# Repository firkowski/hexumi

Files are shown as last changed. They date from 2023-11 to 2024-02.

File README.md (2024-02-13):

# Hexumi
---
Hexumi is a low-cost 3D-printed 18 DoF walking hexapod robot built using Raspberry Pi and ROS2.

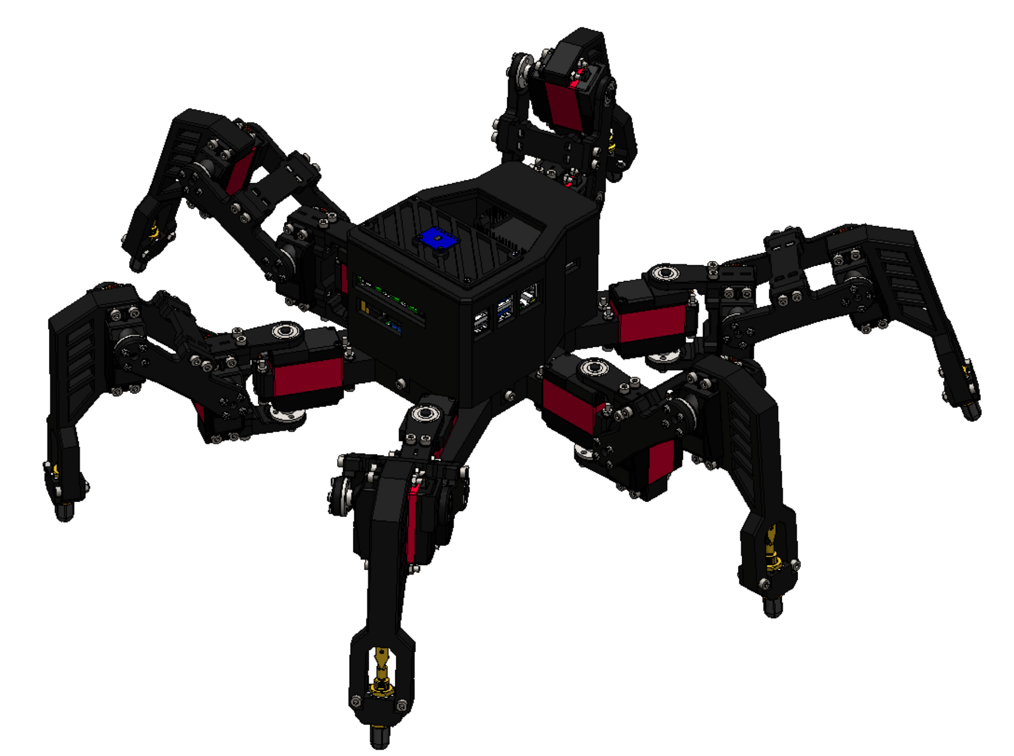
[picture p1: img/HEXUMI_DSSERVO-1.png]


---
## Acknowledgements
The code for Pimoroni Servo2040 servo driver is based on the [C/C++ Pimoroni Pico library](https://github.com/pimoroni/pimoroni-pico) and [micro-ROS](https://github.com/micro-ROS/).

## Documentation
I am currently working on the documentation, assembly instructions, and installation guide, which will be available shortly.

#### Installation (WIP)
The `main` branch contains CAD and STL files. It's meant to be cloned to the development machine.

The `hexumi-base` branch contains minimal code meant to be run directly on the robot.

## Development
For in-depth insights into the development process and detailed build instructions, please refer to my 2023 paper, "Design and Simulation of a Six-Legged Walking Robot", accessible on my [ResearchGate profile](https://www.researchgate.net/profile/Maksymilian-Firkowski/research). Even if you don't intend to replicate Hexumi, the paper provides a valuable roadmap for designing your robot.

## Dependencies
Software in this repo requires ROS2 Humble to run.

To use the Pro Controller, you will have to install [joycond](https://github.com/DanielOgorchock/joycond) on your Raspberry Pi.

Building servo driver's firmware requires the [Pico SDK](https://github.com/raspberrypi/pico-sdk) and [micro-ros-setup](https://github.com/micro-ROS/micro_ros_setup). Remember to export `PICO_SDK_PATH` to point to the folder with the SDK.

---
## Licensing

Code is shared under the MIT license. For details, see [src/LICENSE](src/LICENSE) or [uros/LICENSE](uros/LICENSE).

CAD files, STL files, and the wiring diagram are shared under the Creative Commons Attribution 4.0 License. For details, see [CAD/LICENSE](CAD/LICENSE), [STL/LICENSE](STL/LICENSE), or [img/LICENSE](img/LICENSE).

---
## Why Hexumi?
I designed Hexumi as the subject of my Mechanical Engineering BSc thesis at the Lodz University of Technology, driven by two significant events: the COVID-19 pandemic and the rise of consumer AI. Over the past years, millions of people lost the ability to interact with the outside world due to lockdowns. Simultaneously, the threat of machine learning systems replacing online work loomed. Existing robotic tools for physical labor were either too expensive or lacked sophistication, making them inaccessible to the average person. Thus, I aimed to contribute to the development of affordable robotic solutions for research, education, and entertainment, with the potential to democratize access to mobile and dextrous robots.

### Key Features

- **Cost-efficiency and Accessibility:** Hexumi is designed for easy replication using consumer-grade 3D printing techniques and off-the-shelf electronic components. Depending on your circumstances and 3D printer availability, the build cost can be as low as 300 EUR.

- **Material-efficiency and Sustainability:** The mechanical elements require minimal 3D printing supports, reducing material waste and improving sustainability. Its modular structure ensures that you only need to print minor components when replacements are necessary.

- **Modifiability and Repairability:** Hexumi's components can be easily replaced, whether due to failure or modification. In many cases, only a small amount of material needs to be used for replacements. For example, if you want to change the ground-contact sensors, you only need to modify the tips of the tibias, not the entire links.

- **Software and Sensor Expandability:** Hexumi is designed to operate with the Robot Operating System, preferably ROS2, as its RP2040-based servo driver is well-suited for Micro-ROS. The robot's housing design, a 5V USB power port, and 1.5kg static payload capacity allow mounting additional sensors, such as LIDARs, cameras, IMUs, and more.

- **Ease of Use:** Hexumi was designed to be both modifiable and easy to use. Peripheral components, such as the charging port, provide a simple out-of-the-box experience for a novice user.

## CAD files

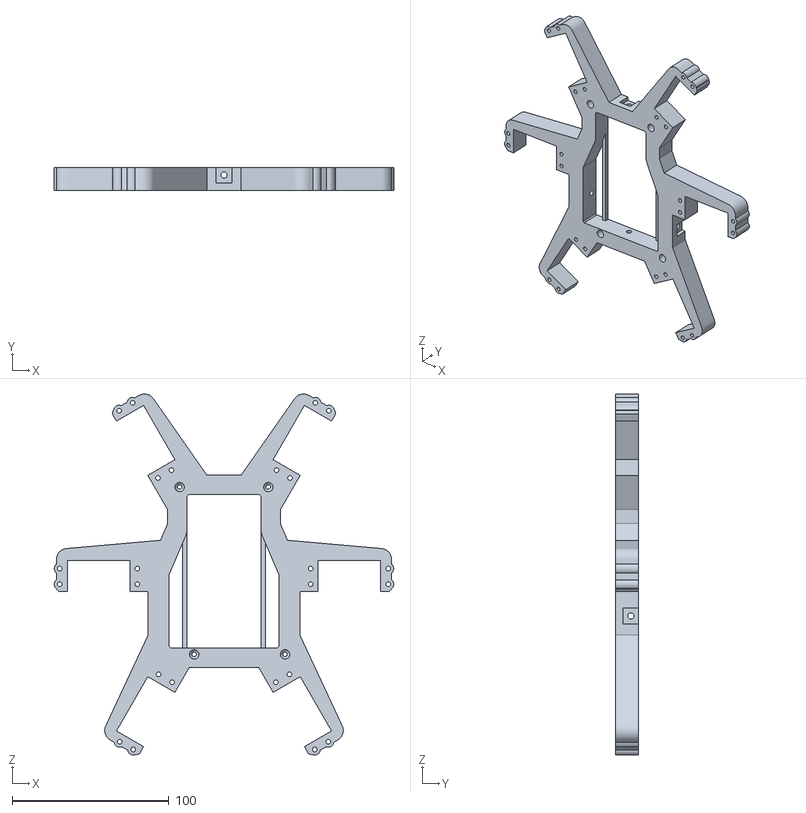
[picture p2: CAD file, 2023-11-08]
STL/MAIN_FRAME.STL
216.8 x 15.0 x 230.5

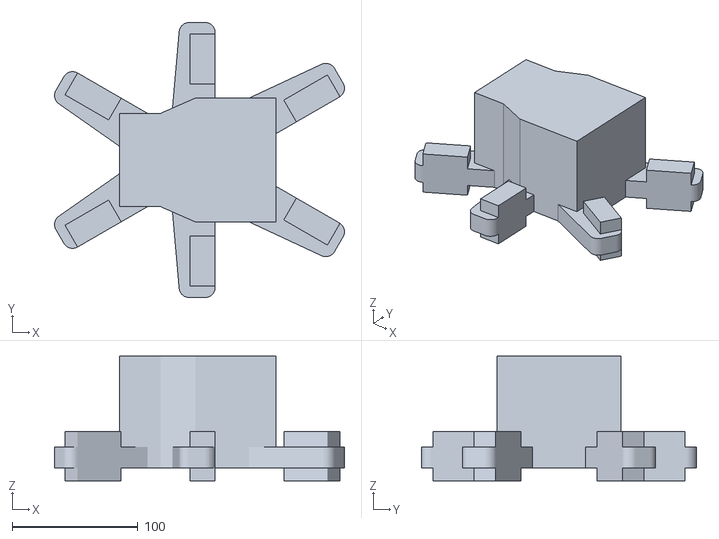
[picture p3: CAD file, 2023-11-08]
src/hexumi_description/meshes/collision/BODY_COLLISIONS.stl
230.3 x 218.5 x 99.0

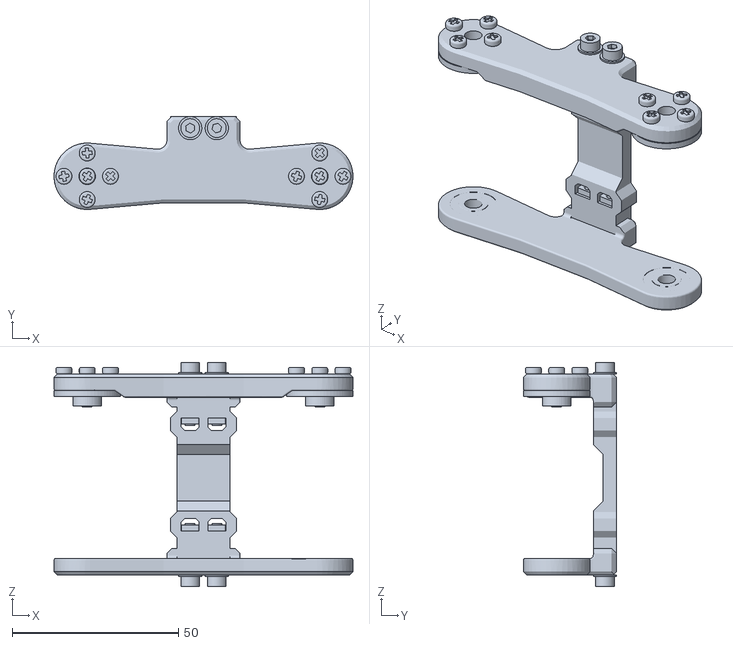
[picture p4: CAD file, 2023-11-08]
src/hexumi_description/meshes/visual/FEMUR_L.stl
90.0 x 28.0 x 67.5

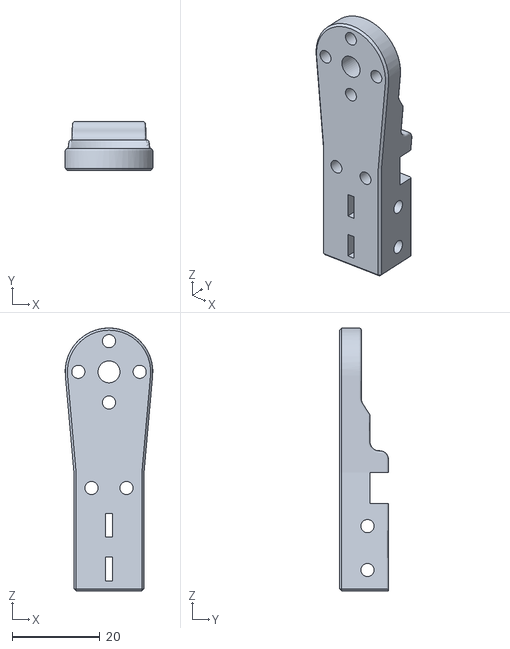
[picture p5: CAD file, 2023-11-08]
STL/COXA_SERVO.STL
20.0 x 11.2 x 60.0

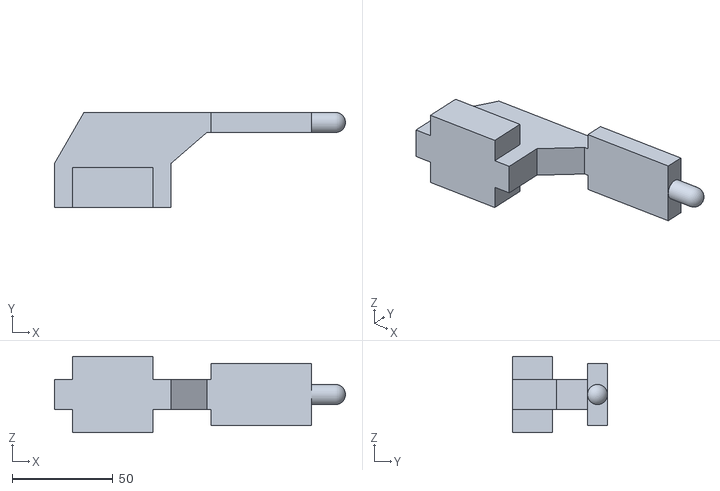
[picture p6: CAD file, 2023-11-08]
src/hexumi_description/meshes/collision/TIBIA_COLLISIONS.stl
144.7 x 47.4 x 38.0

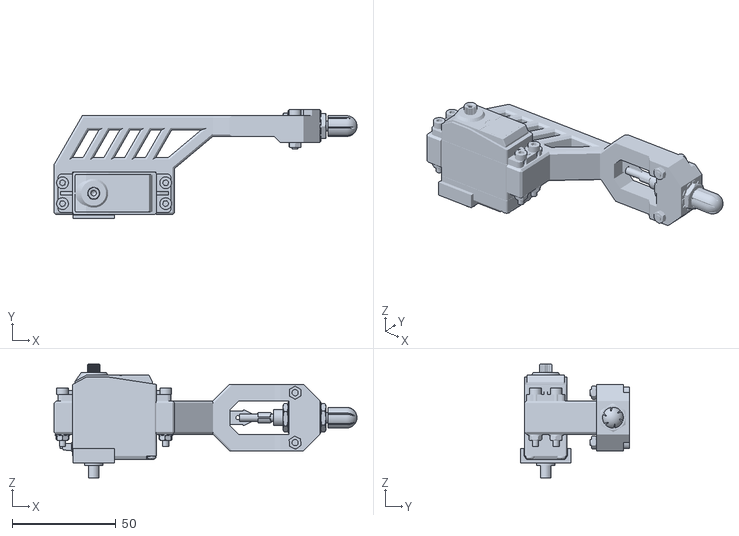
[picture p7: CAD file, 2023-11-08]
src/hexumi_description/meshes/visual/TIBIA_L.stl
145.7 x 52.5 x 54.8

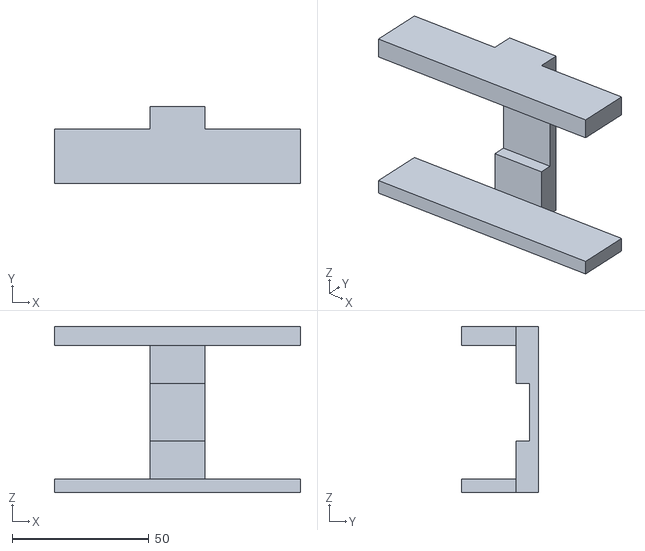
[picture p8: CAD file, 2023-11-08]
src/hexumi_description/meshes/collision/FEMUR_L_COLLISIONS.stl
90.0 x 28.2 x 60.9

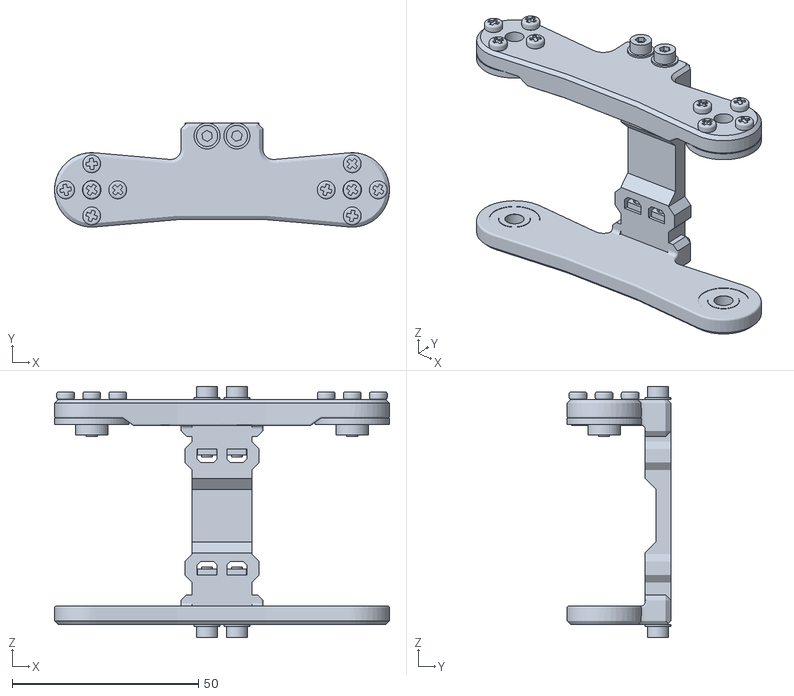
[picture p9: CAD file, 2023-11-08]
src/hexumi_description/meshes/visual/FEMUR.stl
90.0 x 28.0 x 67.5

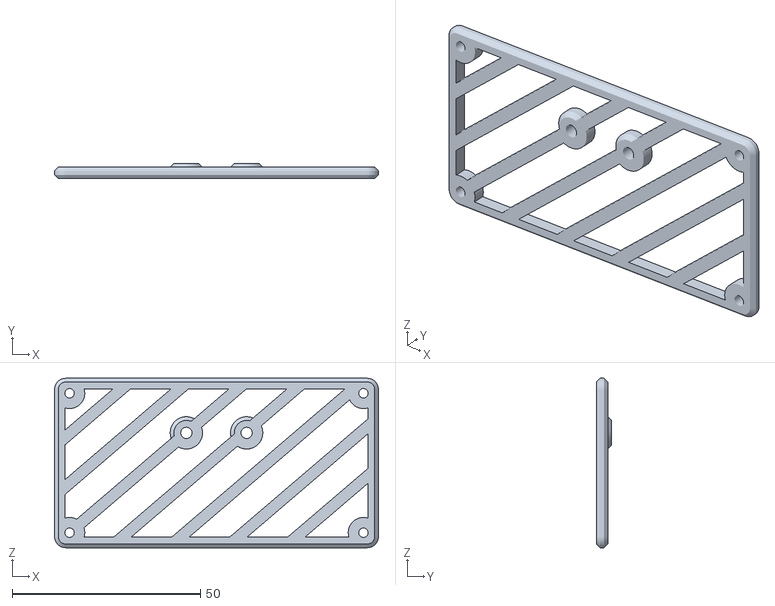
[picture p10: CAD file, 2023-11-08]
STL/MPU6050_STAND.STL
86.0 x 4.00 x 45.0

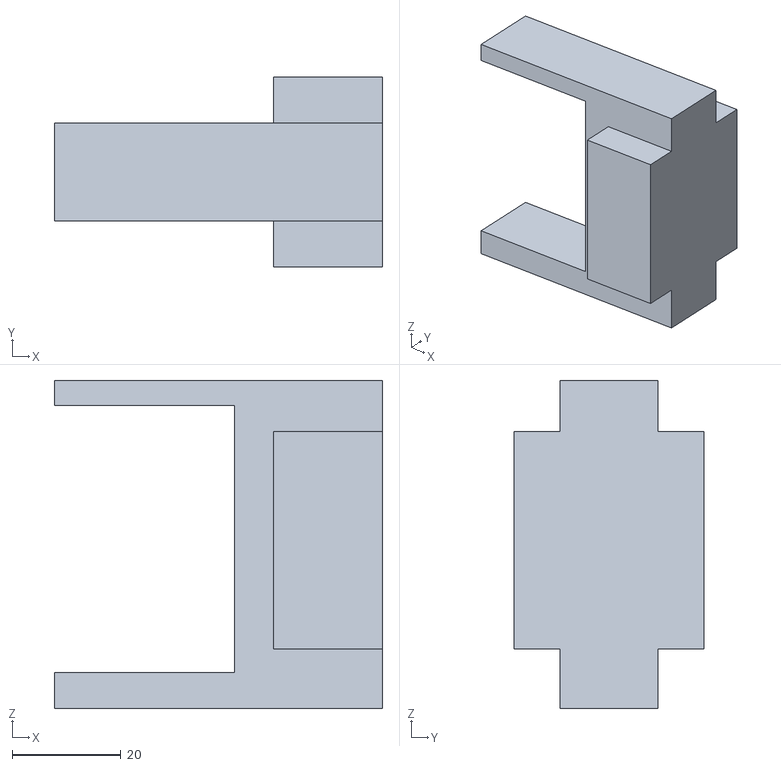
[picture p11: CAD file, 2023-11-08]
src/hexumi_description/meshes/collision/COXA_COLLISIONS.stl
60.3 x 35.0 x 60.3

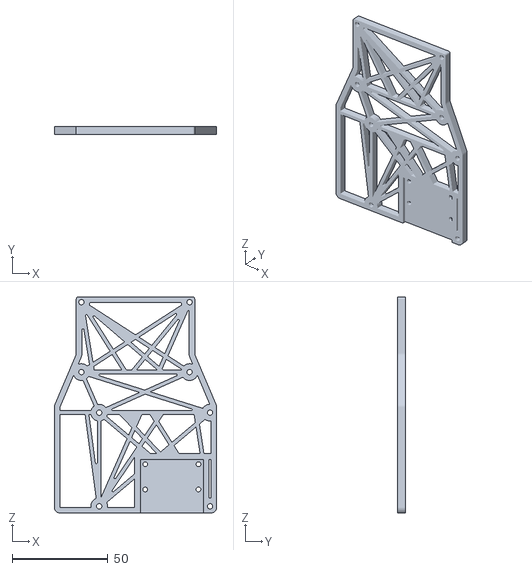
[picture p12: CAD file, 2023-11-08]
STL/RPi FRAME.STL
85.0 x 4.00 x 113.0

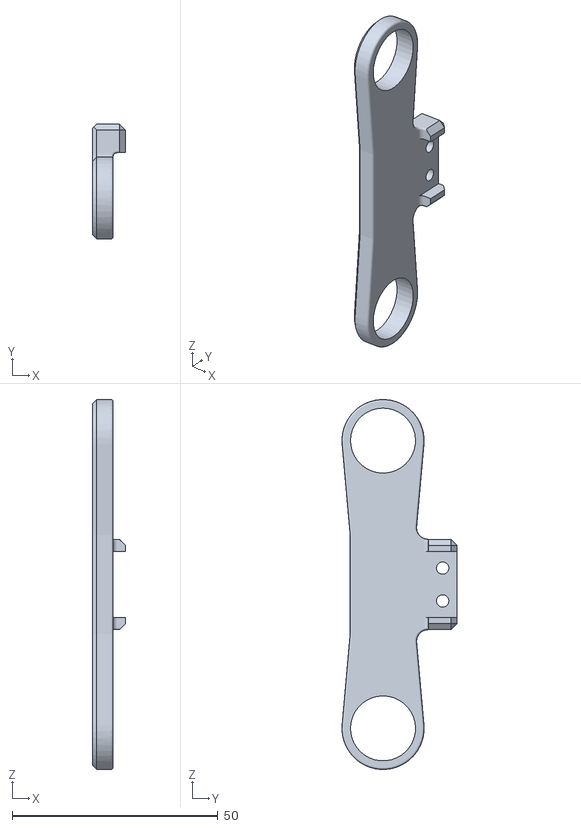
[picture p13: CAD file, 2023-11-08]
STL/FEMUR_BEARING.STL
8.00 x 28.0 x 90.0

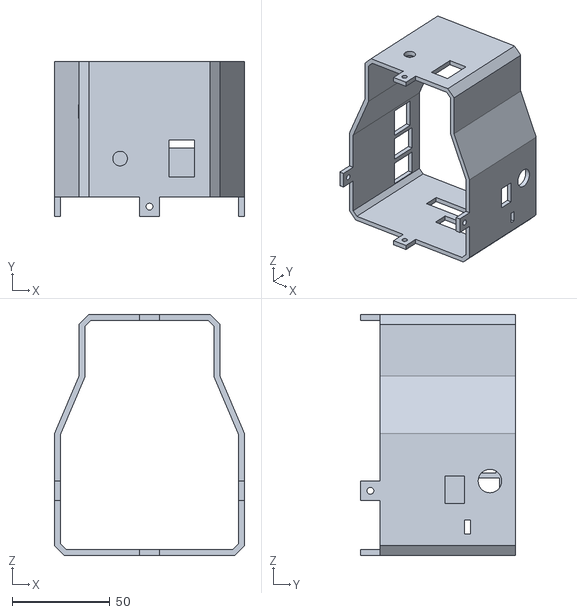
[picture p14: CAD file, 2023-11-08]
STL/MID CASE.STL
97.0 x 79.0 x 123.0

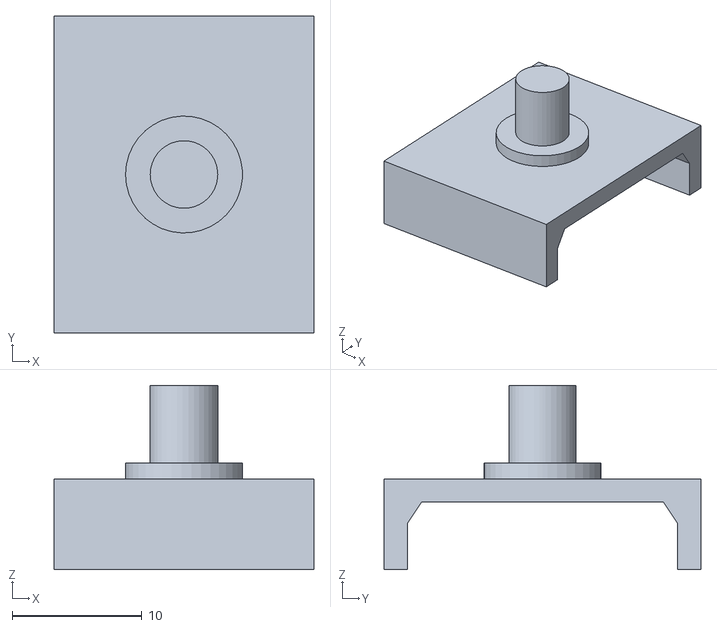
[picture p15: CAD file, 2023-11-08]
STL/SERVO_CLIP.STL
20.0 x 24.4 x 14.2

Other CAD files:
src/hexumi_description/meshes/visual/FEMUR_R.stl
src/hexumi_description/meshes/collision/FEMUR_R_COLLISIONS.stl
src/hexumi_description/meshes/visual/TIBIA_R.stl
STL/COXA_BEARING.STL
STL/FEMUR_SERVO.STL
STL/FOOT_HOLD.STL
STL/LID.step.STL
STL/LINK.STL
STL/POWER_FRAME.STL
STL/TIBIA_V2.STL

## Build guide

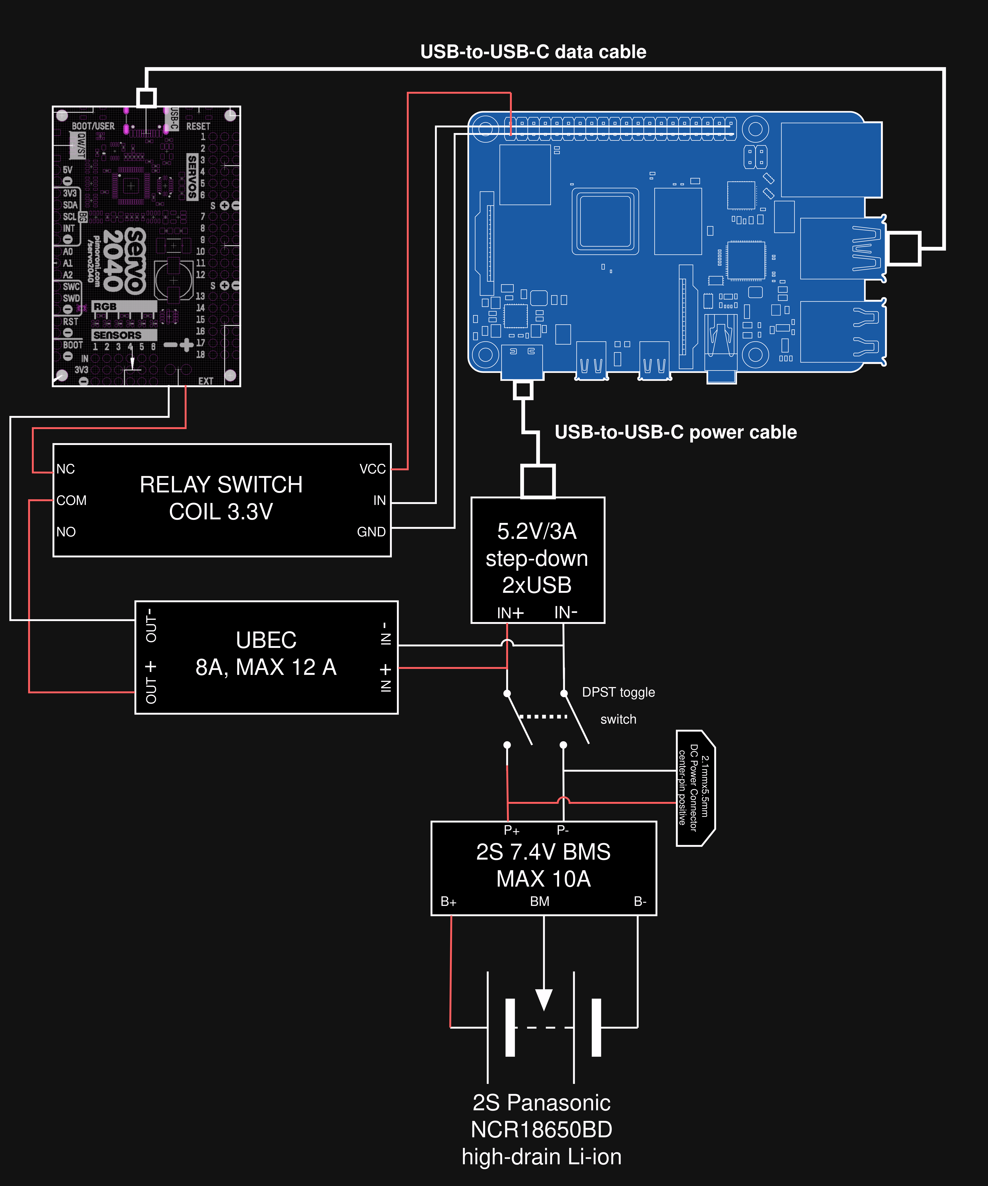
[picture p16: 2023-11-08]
img/wiring diagram.png

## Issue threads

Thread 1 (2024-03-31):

Problem connecting teleop messages to Kinematics node

coop44483, 2024-03-31:
I have down loaded and built the ROS2 project but I seem to be having a problem connecting the teleop node messages to the kinematics node.  I am very new to ROS2.
This is the output of rqt.
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

I hope you or some one else can help tell me what I did wrong!  And more important what I need to do to fix it.

Thank you
David Cooper

coop44483, 2024-03-31:
I just noticed that I have this error when I ran the test.launch.py
[global_parameter_server-5] [INFO] [1711901662.616070235] [global_parameter_server]: Successfully parsed URDF into KDL tree
[ERROR] [hexumi_kinematics-2]: process has died [pid 12146, exit code -11, cmd '/home/dave/hexyws/install/hexumi_kinematics/lib/hexumi_kinematics/hexumi_kinematics --ros-args -r __node:=hexumi_kinematics'].
What does this mean?

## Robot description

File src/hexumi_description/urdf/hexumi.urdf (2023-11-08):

<?xml version="1.0" ?>
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
<robot name="hexumi">
  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
  <link name="base_link"/>
  <joint name="base_joint" type="fixed">
    <parent link="base_link"/>
    <child link="body"/>
    <origin rpy="0 0 0" xyz="0 0 0"/>
  </joint>
  <link name="body">
    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
    <inertial>
      <origin rpy="0 0 0" xyz="-0.02416 0.00018 0.00977"/>
      <mass value="1.07064"/>
      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
    </inertial>
  </link>
  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
  <joint name="virtual_body_joint_R1" type="fixed">
    <origin rpy="0 0 0" xyz="0 0 0"/>
    <parent link="body"/>
    <child link="hip_R1"/>
  </joint>
  <link name="hip_R1">
    <inertial>
      <origin rpy="0 0 0" xyz="0 0 0"/>
      <mass value="0"/>
      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
    </inertial>
  </link>
  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
  <joint name="coxa_joint_R1" type="revolute">
    <origin rpy="0 0 -0.5235987755982988" xyz="0.09526279441628825 -0.05499999999999999 0"/>
    <parent link="hip_R1"/>
    <child link="coxa_R1"/>
    <axis xyz="0 0 1"/>
    <limit effort="100000" lower="-3.141592653589793" upper="3.141592653589793" velocity="10"/>
  </joint>
  <link name="coxa_R1">
    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
    <inertial>
      <origin rpy="0 0 0" xyz="-0.00708 -0.00983 0.02613"/>
      <mass value="0.011045"/>
      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
    </inertial>
  </link>
  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
  <joint name="femur_joint_R1" type="revolute">
    <origin rpy="1.5707963267948966 0 0" xyz="0.04 0 0"/>
    <parent link="coxa_R1"/>
    <child link="femur_R1"/>
    <axis xyz="0 0 1"/>
    <limit effort="100000" lower="-3.141592653589793" upper="3.141592653589793" velocity="10"/>
  </joint>
  <link name="femur_R1">
    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
    <inertial>
      <origin rpy="0 0 0" xyz="0.035 0.00305 0.03111"/>
      <mass value="0.00514"/>
      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
    </inertial>
  </link>
  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
  <joint name="tibia_joint_R1" type="revolute">
    <origin rpy="0 0 0" xyz="0.07 0 0"/>
    <parent link="femur_R1"/>
    <child link="tibia_R1"/>
    <axis xyz="0 0 1"/>
    <limit effort="100000" lower="-3.141592653589793" upper="3.141592653589793" velocity="10"/>
  </joint>
  <link name="tibia_R1">
    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
    <inertial>
      <origin rpy="0 0 0" xyz="0.0286 0.0114 0.00028"/>
      <mass value="0.0013722"/>
      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
    </inertial>
  </link>
  <joint name="end_effector_joint_R1" type="fixed">
    <origin rpy="0 0 0" xyz="0.13 0 0"/>
    <parent link="tibia_R1"/>
    <child link="end_effector_R1"/>
  </joint>
  <link name="end_effector_R1">
    <inertial>
      <origin rpy="0 0 0" xyz="0 0 0"/>
      <mass value="0"/>
      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
    </inertial>
  </link>
  <joint name="virtual_body_joint_R2" type="fixed">
    <origin rpy="0 0 0" xyz="0 0 0"/>
    <parent link="body"/>
    <child link="hip_R2"/>
  </joint>
  <link name="hip_R2">
    <inertial>
      <origin rpy="0 0 0" xyz="0 0 0"/>
      <mass value="0"/>
      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
    </inertial>
  </link>
  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
  <joint name="coxa_joint_R2" type="revolute">
    <origin rpy="0 0 -1.5707963267948966" xyz="5.5109105961630896e-18 -0.09 0"/>
    <parent link="hip_R2"/>
    <child link="coxa_R2"/>
    <axis xyz="0 0 1"/>
    <limit effort="100000" lower="-3.141592653589793" upper="3.141592653589793" velocity="10"/>
  </joint>
  <link name="coxa_R2">
    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
    <inertial>
      <origin rpy="0 0 0" xyz="-0.00708 -0.00983 0.02613"/>
      <mass value="0.011045"/>
      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
    </inertial>
  </link>
  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
  <joint name="femur_joint_R2" type="revolute">
    <origin rpy="1.5707963267948966 0 0" xyz="0.04 0 0"/>
    <parent link="coxa_R2"/>
    <child link="femur_R2"/>
    <axis xyz="0 0 1"/>
    <limit effort="100000" lower="-3.141592653589793" upper="3.141592653589793" velocity="10"/>
  </joint>
  <link name="femur_R2">
    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
    <inertial>
      <origin rpy="0 0 0" xyz="0.035 0.00305 0.03111"/>
      <mass value="0.00514"/>
      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
    </inertial>
  </link>
  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
  <joint name="tibia_joint_R2" type="revolute">
    <origin rpy="0 0 0" xyz="0.07 0 0"/>
    <parent link="femur_R2"/>
    <child link="tibia_R2"/>
    <axis xyz="0 0 1"/>
    <limit effort="100000" lower="-3.141592653589793" upper="3.141592653589793" velocity="10"/>
  </joint>
  <link name="tibia_R2">
    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
    <inertial>
      <origin rpy="0 0 0" xyz="0.0286 0.0114 0.00028"/>
      <mass value="0.0013722"/>
      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
    </inertial>
  </link>
  <joint name="end_effector_joint_R2" type="fixed">
    <origin rpy="0 0 0" xyz="0.13 0 0"/>
    <parent link="tibia_R2"/>
    <child link="end_effector_R2"/>
  </joint>
  <link name="end_effector_R2">
    <inertial>
      <origin rpy="0 0 0" xyz="0 0 0"/>
      <mass value="0"/>
      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
    </inertial>
  </link>
  <joint name="virtual_body_joint_R3" type="fixed">
    <origin rpy="0 0 0" xyz="0 0 0"/>
    <parent link="body"/>
    <child link="hip_R3"/>
  </joint>
  <link name="hip_R3">
    <inertial>
      <origin rpy="0 0 0" xyz="0 0 0"/>
      <mass value="0"/>
      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
    </inertial>
  </link>
  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
  <joint name="coxa_joint_R3" type="revolute">
    <origin rpy="0 0 -2.6179938779914944" xyz="-0.09526279441628825 -0.05499999999999999 0"/>
    <parent link="hip_R3"/>
    <child link="coxa_R3"/>
    <axis xyz="0 0 1"/>
    <limit effort="100000" lower="-3.141592653589793" upper="3.141592653589793" velocity="10"/>
  </joint>
  <link name="coxa_R3">
    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
    <inertial>
      <origin rpy="0 0 0" xyz="-0.00708 -0.00983 0.02613"/>
      <mass value="0.011045"/>
      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
    </inertial>
  </link>
  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
  <joint name="femur_joint_R3" type="revolute">
    <origin rpy="1.5707963267948966 0 0" xyz="0.04 0 0"/>
    <parent link="coxa_R3"/>
    <child link="femur_R3"/>
    <axis xyz="0 0 1"/>
    <limit effort="100000" lower="-3.141592653589793" upper="3.141592653589793" velocity="10"/>
  </joint>
  <link name="femur_R3">
    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
    <inertial>
      <origin rpy="0 0 0" xyz="0.035 0.00305 0.03111"/>
      <mass value="0.00514"/>
      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
    </inertial>
  </link>
  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
  <joint name="tibia_joint_R3" type="revolute">
    <origin rpy="0 0 0" xyz="0.07 0 0"/>
    <parent link="femur_R3"/>
    <child link="tibia_R3"/>
    <axis xyz="0 0 1"/>
    <limit effort="100000" lower="-3.141592653589793" upper="3.141592653589793" velocity="10"/>
  </joint>
  <link name="tibia_R3">
    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
    <inertial>
      <origin rpy="0 0 0" xyz="0.0286 0.0114 0.00028"/>
      <mass value="0.0013722"/>
      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
    </inertial>
  </link>
  <joint name="end_effector_joint_R3" type="fixed">
    <origin rpy="0 0 0" xyz="0.13 0 0"/>
    <parent link="tibia_R3"/>
    <child link="end_effector_R3"/>
  </joint>
  <link name="end_effector_R3">
    <inertial>
      <origin rpy="0 0 0" xyz="0 0 0"/>
      <mass value="0"/>
      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
    </inertial>
  </link>
  <joint name="virtual_body_joint_L1" type="fixed">
    <origin rpy="0 0 0" xyz="0 0 0"/>
    <parent link="body"/>
    <child link="hip_L1"/>
  </joint>
  <link name="hip_L1">
    <inertial>
      <origin rpy="0 0 0" xyz="0 0 0"/>
      <mass value="0"/>
      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
    </inertial>
  </link>
  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
  <joint name="coxa_joint_L1" type="revolute">
    <origin rpy="0 0 0.5235987755982988" xyz="0.09526279441628825 0.05499999999999999 0"/>
    <parent link="hip_L1"/>
    <child link="coxa_L1"/>
    <axis xyz="0 0 1"/>
    <limit effort="100000" lower="-3.141592653589793" upper="3.141592653589793" velocity="10"/>
  </joint>
  <link name="coxa_L1">
    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
    <inertial>
      <origin rpy="0 0 0" xyz="-0.00708 -0.00983 -0.02613"/>
      <mass value="0.011045"/>
      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
    </inertial>
  </link>
  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
  <joint name="femur_joint_L1" type="revolute">
    <origin rpy="1.5707963267948966 0 0" xyz="0.04 0 0"/>
    <parent link="coxa_L1"/>
    <child link="femur_L1"/>
    <axis xyz="0 0 1"/>
    <limit effort="100000" lower="-3.141592653589793" upper="3.141592653589793" velocity="10"/>
  </joint>
  <link name="femur_L1">
    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
    <inertial>
      <origin rpy="0 0 0" xyz="0.035 0.00305 -0.03111"/>
      <mass value="0.00514"/>
      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
    </inertial>
  </link>
  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
  <joint name="tibia_joint_L1" type="revolute">
    <origin rpy="0 0 0" xyz="0.07 0 0"/>
    <parent link="femur_L1"/>
    <child link="tibia_L1"/>
    <axis xyz="0 0 1"/>
    <limit effort="100000" lower="-3.141592653589793" upper="3.141592653589793" velocity="10"/>
  </joint>
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

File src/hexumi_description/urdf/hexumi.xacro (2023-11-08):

<?xml version="1.0"?>
<robot xmlns:xacro="http://www.ros.org/xacro" name="hexumi">

  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
  <xacro:property name="body_length_front_x" value="0.08877" />
  <xacro:property name="body_length_back_x" value="0.1307" />
  <xacro:property name="body_length_y" value="0.23047" />
  <xacro:property name="coxa_length" value="0.04" />
  <xacro:property name="femur_length" value="0.07" />
  <xacro:property name="tibia_length" value="0.13" />
  <xacro:property name="tibia_angle_offset" value="${-pi / 12}" />

  <xacro:property name="body_mass" value="1.07064" />
  <xacro:property name="coxa_mass" value="0.011045" />
  <xacro:property name="femur_mass" value="0.00514" />
  <xacro:property name="tibia_mass" value="0.0013722" />


  <xacro:property name="L1_origin_radius" value="0.11" />
  <xacro:property name="L1_origin_angle" value="${pi / 6}" />
  <xacro:property name="L1_origin_z" value="-0.0075" />

  <xacro:property name="L2_origin_radius" value="0.09" />
  <xacro:property name="L2_origin_angle" value="${pi / 2}" />
  <xacro:property name="L2_origin_z" value="-0.0075" />

  <xacro:property name="L3_origin_radius" value="0.11" />
  <xacro:property name="L3_origin_angle" value="${pi * 5 / 6}" />
  <xacro:property name="L3_origin_z" value="-0.0075" />

  <xacro:property name="R1_origin_radius" value="0.11" />
  <xacro:property name="R1_origin_angle" value="-${pi / 6}" />
  <xacro:property name="R1_origin_z" value="-0.0075" />

  <xacro:property name="R2_origin_radius" value="0.09" />
  <xacro:property name="R2_origin_angle" value="-${pi / 2}" />
  <xacro:property name="R2_origin_z" value="-0.0075" />

  <xacro:property name="R3_origin_radius" value="0.11" />
  <xacro:property name="R3_origin_angle" value="-${pi * 5 / 6}" />
  <xacro:property name="R3_origin_z" value="-0.0075" />

  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
  <xacro:property name="body_x" value="-0.02416" />
  <xacro:property name="body_y" value="0.00018" />
  <xacro:property name="body_z" value="0.00977" />
  <xacro:property name="body_roll" value="0" />
  <xacro:property name="body_pitch" value="0" />
  <xacro:property name="body_yaw" value="0" />
  <xacro:property name="body_ixx" value="0.00329495565" />
  <xacro:property name="body_iyy" value="0.00422550506" />
  <xacro:property name="body_izz" value="0.00610423987" />
  <xacro:property name="body_ixy" value="-0.00000818428" />
  <xacro:property name="body_ixz" value="-0.00007183633" />
  <xacro:property name="body_iyz" value="-0.00002312133" />

  <xacro:property name="coxa_L_x" value="-0.00708" />
  <xacro:property name="coxa_L_y" value="-0.00983" />
  <xacro:property name="coxa_L_z" value="-0.02613" />
  <xacro:property name="coxa_L_roll" value="0" />
  <xacro:property name="coxa_L_pitch" value="0" />
  <xacro:property name="coxa_L_yaw" value="0" />
  <xacro:property name="coxa_L_ixx" value="0.00004537142" />
  <xacro:property name="coxa_L_iyy" value="0.00003512301" />
  <xacro:property name="coxa_L_izz" value="0.00005818289" />
  <xacro:property name="coxa_L_ixy" value="0.00000080668" />
  <xacro:property name="coxa_L_ixz" value="0.00000025971" />
  <xacro:property name="coxa_L_iyz" value="0.00000033767" />

  <xacro:property name="coxa_R_x" value="-0.00708" />
  <xacro:property name="coxa_R_y" value="-0.00983" />
  <xacro:property name="coxa_R_z" value="0.02613" />
  <xacro:property name="coxa_R_roll" value="0" />
  <xacro:property name="coxa_R_pitch" value="0" />
  <xacro:property name="coxa_R_yaw" value="0" />
  <xacro:property name="coxa_R_ixx" value="0.00004537796" />
  <xacro:property name="coxa_R_iyy" value="0.00003512955" />
  <xacro:property name="coxa_R_izz" value="0.00005818289" />
  <xacro:property name="coxa_R_ixy" value="0.00000080667" />
  <xacro:property name="coxa_R_ixz" value="-0.00000026225" />
  <xacro:property name="coxa_R_iyz" value="-0.00000034651" />
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

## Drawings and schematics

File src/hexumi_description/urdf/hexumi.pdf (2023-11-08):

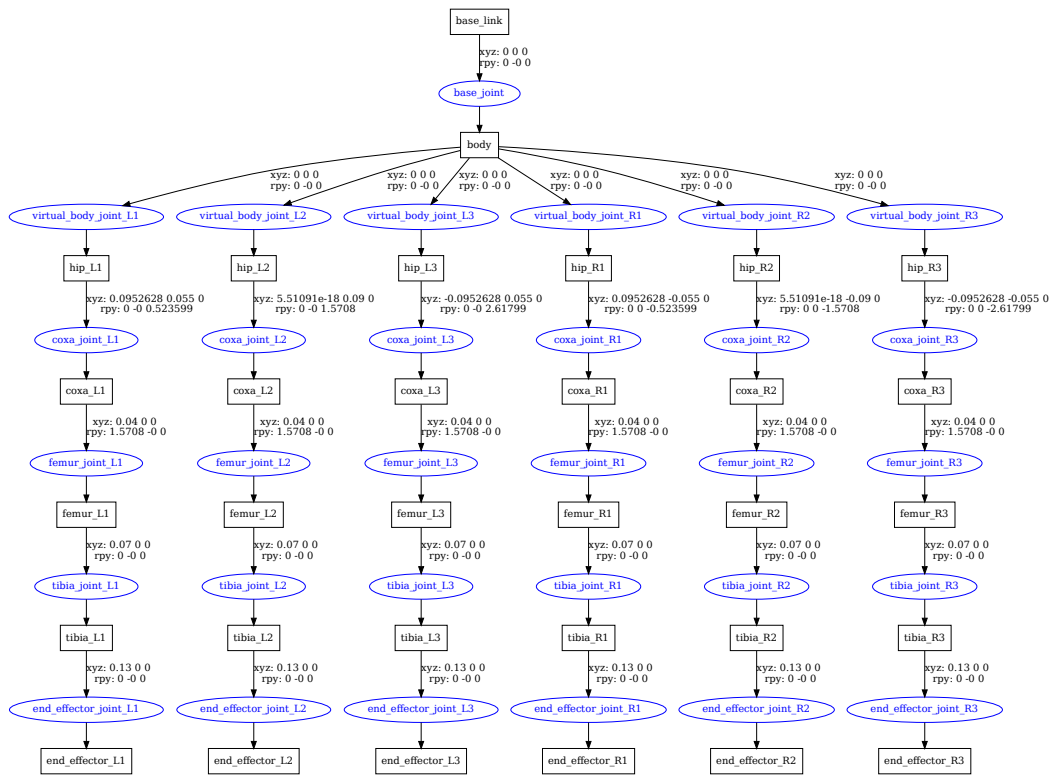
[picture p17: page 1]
base_link; base_joint; xyz: 0 0 0 rpy: 0 -0 0; body; virtual_body_joint_L1; virtual_body_joint_L2; virtual_body_joint_L3; virtual_body_joint_R1; virtual_body_joint_R2; virtual_body_joint_R3; hip_L1; coxa_joint_L1; xyz: 0.0952628 0.055 0 rpy: 0 -0 0.523599; coxa_L1; femur_joint_L1; xyz: 0.04 0 0 rpy: 1.5708 -0 0; femur_L1; tibia_joint_L1; xyz: 0.07 0 0 rpy: 0 -0 0; tibia_L1; end_effector_joint_L1; xyz: 0.13 0 0 rpy: 0 -0 0; end_effector_L1; hip_L2; coxa_joint_L2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

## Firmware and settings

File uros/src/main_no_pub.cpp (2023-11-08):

#include <stdio.h>
#include "pico/stdlib.h"

#include "rclc/rclc.h"

#include <time.h>
#include <vector>
#include <memory>
#include <map>
#include <cmath>

#include "servo2040_uros/msg/feet_contacts.h"
#include "servo2040_uros/msg/current.h"
#include "servo2040_uros/msg/joint_angles.h"
#include "sensor_msgs/msg/joint_state.h"

extern "C"{
#include <rcl/rcl.h>
#include <rcl/error_handling.h>
#include <rclc/rclc.h>
#include <rclc/executor.h>
#include <rmw_microros/rmw_microros.h>

#include "pico_uart_transports.h"
}

#include "servo2040.hpp"
#include "analogmux.hpp"
#include "analog.hpp"
#include "button.hpp"

#define NUM_LEGS 6
#define NUM_SERVOS_PER_LEG 3
#define NUM_SERVOS 18

#define SERVO_L1C 0 //1
#define SERVO_L1F 1 //2
#define SERVO_L1T 2 //3
#define SERVO_L2C 3 //4
#define SERVO_L2F 4 //5
#define SERVO_L2T 5 //6
#define SERVO_L3C 6 //7
#define SERVO_L3F 7 //8
#define SERVO_L3T 8 //9
#define SERVO_R1C 9 //16
#define SERVO_R1F 10 //17
#define SERVO_R1T 11 //18
#define SERVO_R2C 12 //13 
#define SERVO_R2F 13 //14
#define SERVO_R2T 14 //15
#define SERVO_R3C 15 //10
#define SERVO_R3F 16 //11
#define SERVO_R3T 17                                                                                                                                                                                                                     //12

#define WIDE_ANGLE_RANGE 180

#define SENSOR_L1 0
#define SENSOR_L2 1
#define SENSOR_L3 2
#define SENSOR_R1 3
#define SENSOR_R2 4
#define SENSOR_R3 5

#define SENSOR_VOLTAGE_THRESHOLD 2.0

using namespace servo;

std::vector<std::vector<int>> pulses = {
        {550, 1550, 2550}, // L1C, 1
        {460, 1440, 2460}, // L1F, 2
        {580, 1580, 2580}, // L1T, 3
        {580, 1580, 2580}, // L2C, 4
        {585, 1585, 2585}, // L2F, 5
        {455, 1455, 2455}, // L2T, 6
        {500, 1500, 2500}, // L3C, 7
        {475, 1475, 2475}, // L3F, 8
        {500, 1500, 2500}, // L3T, 9
        {580, 1580, 2580}, // R1C, 10
        {500, 1500, 2500}, // R1F, 11
        {580, 1580, 2580}, // R1T, 12
        {550, 1550, 2550}, // R2C, 13
        {470, 1470, 2470}, // R2F, 14
        {540, 1540, 2540}, // R2T, 15
        {520, 1520, 2520}, // R3C, 16
        {650, 1650, 2650}, // R3F, 17
        {610, 1650, 2610}  // R3T, 18
    };


std::map<int, int> servo_IDs {
	{0, SERVO_L1C},
	{1, SERVO_L1F},
	{2, SERVO_L1T},
	{3, SERVO_L2C},
	{4, SERVO_L2F},
	{5, SERVO_L2T},
	{6, SERVO_L3C},
	{7, SERVO_L3F},
	{8, SERVO_L3T},
	{9, SERVO_R3C},
	{10, SERVO_R3F},
	{11, SERVO_R3T},
	{12, SERVO_R2C},
	{13, SERVO_R2F},
	{14, SERVO_R2T},
	{15, SERVO_R1C},
	{16, SERVO_R1F},
	{17, SERVO_R1T},
};

std::map<int, int> sensor_IDs {
	{0,  SENSOR_L1},
	{1,  SENSOR_L2},
	{2,  SENSOR_L3},
	{3,  SENSOR_R1},
	{4,  SENSOR_R2},
	{5,  SENSOR_R3}
};

rcl_publisher_t    feet_contacts_pub_;
rcl_publisher_t    current_pub_;
rcl_subscription_t joint_angles_sub_;
servo2040_uros__msg__FeetContacts   feet_contacts_msg;
servo2040_uros__msg__Current current_msg;
servo2040_uros__msg__JointAngles    joint_angles_msg;

rcl_publisher_t	joint_state_pub_;
sensor_msgs__msg__JointState		 joint_state_msg;

enum states {
  WAITING_AGENT,
  AGENT_AVAILABLE,
  AGENT_CONNECTED,
  AGENT_DISCONNECTED
} state;

rcl_timer_t timer;
rcl_node_t node;
rcl_allocator_t allocator;
rclc_support_t support;
rclc_executor_t executor;

const uint START_PIN = 0;
const uint END_PIN = NUM_SERVOS;
ServoCluster servos = ServoCluster(pio0, 0, START_PIN, END_PIN);
std::array<std::unique_ptr<Calibration>, NUM_SERVOS> cals;

Analog sen_adc = Analog(servo2040::SHARED_ADC);
Analog vol_adc = Analog(servo2040::SHARED_ADC, servo2040::VOLTAGE_GAIN);
Analog cur_adc = Analog(servo2040::SHARED_ADC, servo2040::CURRENT_GAIN,
                        servo2040::SHUNT_RESISTOR, servo2040::CURRENT_OFFSET);

AnalogMux mux = AnalogMux(servo2040::ADC_ADDR_0, servo2040::ADC_ADDR_1, servo2040::ADC_ADDR_2,
                          PIN_UNUSED, servo2040::SHARED_ADC);

float angle_map(int i, float deg) {
	float angle = deg;
	int side = (i < (NUM_SERVOS / 2)) ? 1 : -1;
	// 0 for C, 1 for F, 2 for T
	int joint = i % 3;

	switch (joint) {
		case 0:
			break;
		case 1:
			angle *= side;
			break;
		case 2:
			angle = -side*(angle + 90.0);
			break;
	}
	return angle;
}

void init() {

	servos.init();

	for (int i = 0; i < NUM_SERVOS; i++) {
		Calibration &cal_ref = servos.calibration(i);
		cal_ref.apply_three_pairs(pulses[i][0], pulses[i][1], pulses[i][2],
                                        -90.0,            0,         90.0);
	}

	servos.enable_all();

	for(auto i = 0u; i < servo2040::NUM_SENSORS; i++) {
   		mux.configure_pulls(servo2040::SENSOR_1_ADDR + i, false, true);
  	}

	joint_state_msg.position.capacity = NUM_SERVOS;
	joint_state_msg.position.data = (double*) malloc(joint_state_msg.position.capacity * sizeof(double));
	joint_state_msg.position.size = 0;

	for (int i = 0; i < NUM_SERVOS; i++) {
		joint_state_msg.position.data[i] = 0.0;
		joint_state_msg.position.size++;
	}

	rcl_ret_t feet_contacts_ret = rcl_publish(&joint_state_pub_, &joint_state_msg, NULL);

}

void timer_callback(rcl_timer_t * timer, int64_t last_call_time)
{	
	
}

void subscription_callback(const void * msgin)
{
	const servo2040_uros__msg__JointAngles * msg = (const servo2040_uros__msg__JointAngles *)msgin;

	if (msg == NULL) 
		return;

    for (size_t i = 0; i < NUM_SERVOS; i++) {
		int j = servo_IDs[i];
		float deg = static_cast<float>(msg->joint_angles[i]) * 180.0 / M_PI;
		//joint_state_msg.position.data[i] = deg;

		float angle = angle_map(j, deg);
		servos.value(j, angle);
    }
	//rcl_ret_t feet_contacts_ret = rcl_publish(&joint_state_pub_, &joint_state_msg, NULL);
}

bool pingAgent(){
    const int timeout_ms = 1000;
    const uint8_t attempts = 10;

    rcl_ret_t ret = rmw_uros_ping_agent(timeout_ms, attempts);

    if (ret != RCL_RET_OK){
    	return false;
    } 
    return true;
}

void createEntities() {

	allocator = rcl_get_default_allocator();
	rclc_support_init(&support, 0, NULL, &allocator);

	rclc_node_init_default(&node, "servo2040_node", "", &support);

	rclc_subscription_init_default(
		&joint_angles_sub_,
		&node,
		ROSIDL_GET_MSG_TYPE_SUPPORT(servo2040_uros, msg, JointAngles),
		"/joint_angles");

	rclc_timer_init_default(
		&timer,
		&support,
		RCL_MS_TO_NS(100),
		timer_callback);

	// create publishers
	/*
	rclc_publisher_init_default(
		&feet_contacts_pub_,
		&node,
		ROSIDL_GET_MSG_TYPE_SUPPORT(servo2040_uros, msg, FeetContacts),
		"/servo2040/feet_contacts");

	rclc_publisher_init_default(
		&joint_state_pub_,
		&node,
		ROSIDL_GET_MSG_TYPE_SUPPORT(sensor_msgs, msg, JointState),
		"/servo2040/joint_states");
    
    rclc_publisher_init_default(
		&current_pub_,
		&node,
		ROSIDL_GET_MSG_TYPE_SUPPORT(servo2040_uros, msg, Current),
		"/servo2040/current");
	*/
	rclc_executor_init(&executor, &support.context, 2, &allocator);
	rclc_executor_add_timer(&executor, &timer);

	rclc_executor_add_subscription(&executor,
			&joint_angles_sub_,
			&joint_angles_msg,
			&subscription_callback,
			ON_NEW_DATA);
}

void destroyEntities(){
	rmw_context_t * rmw_context = rcl_context_get_rmw_context(&support.context);
	(void) rmw_uros_set_context_entity_destroy_session_timeout(rmw_context, 0);

	//rcl_publisher_fini(&feet_contacts_pub_, &node);
	//rcl_publisher_fini(&current_pub_, &node);
	//rcl_publisher_fini(&joint_state_pub_, &node);
	rcl_subscription_fini(&joint_angles_sub_, &node);
	rcl_timer_fini(&timer);
	rclc_executor_fini(&executor);
	rcl_node_fini(&node);
	rclc_support_fini(&support);
}


int main()
{	
	stdio_init_all();

	init();

    rmw_uros_set_custom_transport(
		true,
		NULL,
		pico_serial_transport_open,
		pico_serial_transport_close,
		pico_serial_transport_write,
		pico_serial_transport_read
	);
	
  	state = WAITING_AGENT;

	while (true){
    	switch (state) {
    	    case WAITING_AGENT:
    	      state = pingAgent() ? AGENT_AVAILABLE : WAITING_AGENT;
    	      break;
    	    case AGENT_AVAILABLE:
    	      createEntities();
    	      state = AGENT_CONNECTED ;
    	      break;
    	    case AGENT_CONNECTED:
    	      state = pingAgent() ? AGENT_CONNECTED : AGENT_DISCONNECTED;
    	      if (state == AGENT_CONNECTED) {
    	        rclc_executor_spin(&executor);
    	      }
    	      break;
    	    case AGENT_DISCONNECTED:
    	      destroyEntities();
    	      state = WAITING_AGENT;
    	      break;
    	    default:
    	      break;
    	  }
    }
}

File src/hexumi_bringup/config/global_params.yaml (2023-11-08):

global_parameter_server:
  ros__parameters:
    robot_description: "$(find-pkg-share hexumi_description)/urdf/hexumi.xacro"

    robot_name: "Hexumi"

    num_legs: 6

    num_leg_joints: 3

    leg_suffixes: ["R1", "R2", "R3", "L3", "L2", "L1"]

    #leg_suffixes: ["L1", "L2", "L3", "R1", "R2", "R3"]

# link info
    tibia_angle_offset_deg: -15.0

#joint limits
    coxa_joint_upper_limit : 90.0
    coxa_joint_lower_limit : -90.0
    femur_joint_upper_limit : 90.0
    femur_joint_lower_limit : -90.0
    tibia_joint_upper_limit : 0.0
    tibia_joint_lower_limit : -180.0

# default sitting position 
    #L1_sitting_radius: 0.215
    #L2_sitting_radius: 0.195
    #L3_sitting_radius: 0.215

    #R1_sitting_radius: 0.215
    #R2_sitting_radius: 0.195
    #R3_sitting_radius: 0.215

    L1_sitting_radius: 0.235
    L2_sitting_radius: 0.225
    L3_sitting_radius: 0.235

    R1_sitting_radius: 0.235
    R2_sitting_radius: 0.225
    R3_sitting_radius: 0.235

    leg_sitting_z: -0.035

# teleop limits
    max_lin_velocity : 0.1
    
    max_ang_velocity : 0.4

    max_body_x_euler : 0.0
    
    max_body_y_euler : 0.15
    
    max_body_z_euler : 0.15
    
    max_body_x : 0.04
    
    max_body_y : 0.04

    max_body_z : 0.1
    
    max_body_velocity_z : 0.1

# gait params
    transfer_height: 0.04

    max_obstacle_height: 0.04

    workspace_ellipse_axes: [0.150, 0.130, 0.115]

    workspace_ellipse_origin: [0.120, 0.0, -0.109]

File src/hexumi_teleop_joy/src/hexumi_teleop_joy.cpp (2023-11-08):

#include "hexumi_teleop_joy.hpp"

using namespace std::chrono_literals;

TeleopJoy::TeleopJoy() 
: Node("hexumi_teleop_joy") {
    press_to_power_on_duration = 3.0;
    
    parameters_client_ = std::make_shared<rclcpp::AsyncParametersClient>(this, "/global_parameter_server");
    
    RCLCPP_INFO(rclcpp::get_logger("rclcpp"), "Waiting for global parameter server to be available...");
    parameters_client_->wait_for_service();

    auto parameters_future = parameters_client_->get_parameters({"max_lin_velocity", 
                                                                "max_ang_velocity",
                                                                "max_body_y_euler",
                                                                "max_body_z_euler",
                                                                "max_body_x",
                                                                "max_body_y",
                                                                "max_body_velocity_z"},
            std::bind(&TeleopJoy::set_params_from_global_param_server, this, std::placeholders::_1));

    servo_power_flag     = false;
    start_flag           = false;
    imu_flag             = false;

    startTime = std::chrono::steady_clock::now();

    joy_sub_ = create_subscription<sensor_msgs::msg::Joy>(
        "/joy", 1, std::bind(&TeleopJoy::joyCallback, this, std::placeholders::_1));

    body_control_pub_   = create_publisher<hexumi_msgs::msg::BodyControl>("/teleop/body_control", 1);           // body pose
    hexapod_motion_pub_ = create_publisher<hexumi_msgs::msg::HexapodMotion>("/teleop/hexapod_motion", 1); // low lever power, stand up, sit down stuff
    meta_cmd_pub_       = create_publisher<hexumi_msgs::msg::MetaCommands>("/teleop/meta_cmd", 1);        // twist  of {b} or direction of {b}, motion type 
}
void TeleopJoy::set_params_from_global_param_server(std::shared_future<std::vector<rclcpp::Parameter>> future) {
    // get params from global param server
    max_lin_velocity    = future.get()[0].as_double();
    max_ang_velocity    = future.get()[1].as_double();
    max_body_y_euler    = future.get()[2].as_double();
    max_body_z_euler    = future.get()[3].as_double();
    max_body_x          = future.get()[4].as_double();
    max_body_y          = future.get()[5].as_double();
    max_body_velocity_z = future.get()[6].as_double();
}

// sets control flags depending on joy input
void TeleopJoy::setJoyFlags(const sensor_msgs::msg::Joy::SharedPtr &joy){
    servo_power_off_command_flag = joy->buttons[button_H] && servo_power_flag; // press
    servo_power_on_command_flag  = joy->buttons[button_ZR] && joy->buttons[button_ZL] && !servo_power_flag; // hold
    start_command_flag           = joy->buttons[button_B]; // press
    imu_on_off_command_flag      = joy->buttons[button_O]; // press
    omnidirectional_command_flag = joy->buttons[button_R]; // hold
    wave_gait_command_flag       = joy->buttons[button_Y]; // press 
    ripple_gait_command_flag     = joy->buttons[button_X]; // press
    tripod_gait_command_flag     = joy->buttons[button_A]; // press
}

// DEFINITIONS OF CONTROL METHODS
void TeleopJoy::servoPowerOn() {
    servo_power_flag = true;
    meta_cmd.power = true;
    meta_cmd_pub_->publish(meta_cmd);
    rclcpp::sleep_for(1000ms);
}

void TeleopJoy::servoPowerOff() {
    servo_power_flag = false;
    meta_cmd.power = false;
    start_flag = false;
    meta_cmd.is_ready = false;
    imu_flag = false;
    meta_cmd.imu_status = false;
    meta_cmd_pub_->publish(meta_cmd);
    rclcpp::sleep_for(1000ms);
}

void TeleopJoy::scanForPowerOn() {
    auto currentTime = std::chrono::steady_clock::now();

    auto duration = std::chrono::duration_cast<std::chrono::seconds>(currentTime - startTime);

    if (duration.count() >= press_to_power_on_duration) 
        servoPowerOn();
}

//stand up or sit down
void TeleopJoy:: startStop() {
    start_flag ^= 1;
    meta_cmd.is_ready ^= 1;
    if (!start_flag) {
        imu_flag = false;
        meta_cmd.imu_status =false;
    }
    meta_cmd_pub_->publish(meta_cmd);
    rclcpp::sleep_for(1000ms);
}

void TeleopJoy::imuOnOff() {
    imu_flag ^= 1;
    meta_cmd.imu_status ^= 1;
    meta_cmd_pub_->publish(meta_cmd);
    rclcpp::sleep_for(1000ms);
}

// set motion type (omni vs stream)
void TeleopJoy::setOmnidirectional() {
    hexapod_motion.motion_type = hexumi_msgs::msg::HexapodMotion::MOTION_OMNI;
    hexapod_motion_pub_->publish(hexapod_motion);
    // sleep here ???
}

void TeleopJoy::setStreamlined() {
    hexapod_motion.motion_type = hexumi_msgs::msg::HexapodMotion::MOTION_STREAM;
    hexapod_motion_pub_->publish(hexapod_motion);
    // sleep here ??
}

// set gait (wave, ripple, tripod)
void TeleopJoy::setGaitWave() {
    hexapod_motion.gait= hexumi_msgs::msg::HexapodMotion::WAVE_GAIT;
    hexapod_motion_pub_->publish(hexapod_motion);
}

void TeleopJoy::setGaitRipple() {
    hexapod_motion.gait= hexumi_msgs::msg::HexapodMotion::RIPPLE_GAIT;
    hexapod_motion_pub_->publish(hexapod_motion);
}

void TeleopJoy::setGaitTripod() {
    hexapod_motion.gait= hexumi_msgs::msg::HexapodMotion::TRIPOD_GAIT;
    hexapod_motion_pub_->publish(hexapod_motion);
}

// find hexapod motion data
// find body control
void TeleopJoy::setBodyPose(double s_xR, double s_yR, int R_button_state) {
    if (R_button_state == 1.0) {
        body_control.body_pose_euler_angles.euler_angles.z = 0.0;
        body_control.body_pose_euler_angles.euler_angles.y = 0.0;
        body_control.body_pose_euler_angles.euler_angles.x = 0.0;

        body_control.body_pose_euler_angles.position.x = -s_xR * max_body_x;
        body_control.body_pose_euler_angles.position.y = s_yR * max_body_y;
        body_control.body_pose_euler_angles.position.z = 0.0;
    }
    else {
        body_control.body_pose_euler_angles.euler_angles.z = s_yR * max_body_z_euler;
        body_control.body_pose_euler_angles.euler_angles.y = s_xR * max_body_y_euler;
        body_control.body_pose_euler_angles.euler_angles.x = 0.0;

        body_control.body_pose_euler_angles.position.x = 0.0;
        body_control.body_pose_euler_angles.position.y = 0.0;
        body_control.body_pose_euler_angles.position.z = 0.0;
    }
}

// ZYX rotation, Quaterions in JPL convention
void TeleopJoy::setBodyTwist(double z_relative) {
    body_control.body_twist.angular.x = 0.0;
    body_control.body_twist.angular.y = 0.0;
    body_control.body_twist.angular.z = 0.0;

    body_control.body_twist.linear.x  = 0.0;
    body_control.body_twist.linear.y  = 0.0;
    body_control.body_twist.linear.z = z_relative * max_body_velocity_z;
}
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

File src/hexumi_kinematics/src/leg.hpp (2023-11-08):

#pragma once

#include <kdl/frames.hpp>
#include <vector>
#include <kdl/rotational_interpolation_sa.hpp>
#include <kdl/path.hpp>
#include <kdl/path_line.hpp>
#include <kdl/path_circle.hpp>
#include <kdl/path_composite.hpp>
#include <kdl/path_point.hpp>
#include <kdl/velocityprofile_trap.hpp>
#include <kdl/velocityprofile_rect.hpp>
#include <kdl/trajectory_segment.hpp>
#include <kdl/trajectory_stationary.hpp>
#include "kdl/utilities/error.h"

#include "hexapod_paths.hpp"

#include <rclcpp/rclcpp.hpp>

#include <cmath>
#include <memory>

#define ANGULAR_DEADZONE 0.02
#define NUM_SAMPLES 200
#define MAX_DURATION 10

double KDL::epsilon = 1e-9;

class Leg;
class EllipsoidWorkspace;

class EllipsoidWorkspace {
public: 
    EllipsoidWorkspace(KDL::Frame leg_origin) {center_b = leg_origin * center_l;};
    KDL::Vector getCenterL() const {return center_l;};
    KDL::Vector getCenterB() const {return center_b;};
    std::vector<double> getAxes() const {return axes;};
    double a() const {return axes[0];};
    double b() const {return axes[1];};
    double c() const {return axes[2];};

    static void setCenterL(KDL::Vector ctr) {center_l = ctr;};
    static void setAxes(std::vector<double> ax) {axes = ax;};

    static KDL::Vector center_l;
    static std::vector<double> axes;

private:
    KDL::Vector center_b;
};
KDL::Vector EllipsoidWorkspace::center_l = KDL::Vector(0.0, 0.0, 0.0); 
std::vector<double> EllipsoidWorkspace::axes = {0.0, 0.0, 0.0};


class Leg{
public:

    Leg(int id, 
         float coxa_length, float femur_length, float tibia_length,
         KDL::Frame T_origin, 
         KDL::Vector sitting_positionB)  : id(id),
                                          coxa_length(coxa_length),
                                          femur_length(femur_length),
                                          tibia_length(tibia_length),
                                          T_origin(T_origin),
                                          sitting_position_b(sitting_positionB),
                                          workspace(T_origin) {
        sitting_position_l = to_hip_frame(sitting_position_b);
        setPositionB(sitting_position_b);
        null_position_l = workspace.getCenterL();
        null_position_b = to_body_frame(null_position_l);

        traj_type = support;

        path = new KDL::Path_Point(KDL::Frame(KDL::Rotation::Identity(), current_position_b));
        velprof = new KDL::VelocityProfile_Rectangular(0.0);

        duration = 0;

        KDL::Frame current_frame_b = KDL::Frame::Identity();
        current_frame_b.p = current_position_b;
        traj = new KDL::Trajectory_Stationary(KDL::epsilon, current_frame_b);
    };

    ~Leg() {
        delete path;
        delete velprof;
        delete traj;
    };

    int getId() const {return id;};
    bool setPositionB(KDL::Vector);
    bool setPositionL(KDL::Vector);

    bool isInTaskspaceB(KDL::Vector);
    bool isInTaskspaceL(KDL::Vector);
    bool isInWorkspaceB(KDL::Vector);
    bool isInWorkspaceL(KDL::Vector);
    
    KDL::Vector getCurrentPositionB() const {return current_position_b;}
    KDL::Vector getCurrentPositionL() const {return current_position_l;}
    KDL::Vector getSittingPositionB() const {return sitting_position_b;}
    KDL::Vector getSittingPositionL() const {return sitting_position_l;}
    KDL::Vector getNullPositionB()    const {return null_position_b;}
    KDL::Vector getNullPositionL()    const {return null_position_l;}
    
    std::vector<float> getJointAngles() const {return current_joint_angles;}
    float getCoxaAngle()                const {return coxa_angle;}
    float getFemurAngle()               const {return femur_angle;}
    float getTibiaAngle()               const {return tibia_angle;}

    bool isSingular() const {return singularity_flag;}

    void activate()   {is_active = true;}
    void deactivate() {is_active = false;}
    bool isActive()   {return is_active;}

    //debug 
    EllipsoidWorkspace getWorkspace() const {return workspace;}

    static void setMotionParams(KDL::Twist, KDL::Frame);

    void generateSupportPath();
    void generateTransferPathCenter(double, double);

    void resetDuration() {duration = 0;}

    KDL::Path* path;
    KDL::VelocityProfile* velprof;
    KDL::Trajectory* traj;
    
    static int tripodPhase;
    static int wavePhase;
    static int ripplePhase;

    double duration;

    static KDL::Twist motion_twist;
    static KDL::Frame body_pose;

private:

    KDL::RotationalInterpolation_SingleAxis rotinterp;

    int id;
    float coxa_length, femur_length, tibia_length;
    KDL::Frame T_origin; // pose of leg's hip frame wrt. body frame
    KDL::Vector sitting_position_b;
    KDL::Vector sitting_position_l;

    KDL::Vector current_position_l;
    KDL::Vector current_position_b;
    KDL::Vector null_position_l;
    KDL::Vector null_position_b;

    KDL::Vector to_hip_frame(KDL::Vector p_b)  {return T_origin.Inverse(p_b);};
    KDL::Frame  to_hip_frame(KDL::Frame  T_b)  {return T_origin.Inverse() * T_b;};
    KDL::Vector to_body_frame(KDL::Vector p_l) {return T_origin*p_l;};
    KDL::Frame  to_body_frame(KDL::Frame  T_l) {return T_origin*T_l;};

    void set_joint_angles();
    std::vector<float> current_joint_angles;
    float coxa_angle, femur_angle, tibia_angle;

    bool singularity_flag;

    bool is_active;

    EllipsoidWorkspace workspace;

    enum TrajType {support, transfer} traj_type;
    KDL::Path* point_path();
    KDL::Path* line_path();
    KDL::Path* arc_path(KDL::Vector);
    static double path_length;
    static double path_angle;
};

double Leg::path_length = 0.0;
double Leg::path_angle = 0.0;

KDL::Twist Leg::motion_twist = KDL::Twist::Zero();
KDL::Frame Leg::body_pose = KDL::Frame::Identity();
int Leg::tripodPhase = 0;
int Leg::wavePhase = 0;
int Leg::ripplePhase = 0;

bool Leg::isInTaskspaceL(KDL::Vector p_l) {
    KDL::Vector vec = p_l - workspace.getCenterL();
    return (std::pow(vec.x(), 2) / std::pow(workspace.a()/2, 2) + 
            std::pow(vec.y(), 2) / std::pow(workspace.b()/2, 2) + 
            std::pow(vec.z(), 2) / std::pow(workspace.c()/2, 2)) <= 1;
}

bool Leg::isInTaskspaceB(KDL::Vector p_b) {
    return isInTaskspaceL(to_hip_frame(p_b));
}

bool Leg::setPositionL(KDL::Vector p_l) {
    if (isInWorkspaceL(p_l)) {
        current_position_l = p_l;
        current_position_b = to_body_frame(p_l);
        set_joint_angles();
        return true;
    }
    else {
        return false;
    }
}

bool Leg::setPositionB(KDL::Vector p_b) {
    return setPositionL(to_hip_frame(p_b));
}

bool Leg::isInWorkspaceL(KDL::Vector p_l) {
    float leg_radius = p_l.Norm();

    return (   leg_radius                     <= tibia_length + femur_length
            && leg_radius                     >= tibia_length - femur_length
            && std::atan2( p_l.y(), p_l.x() ) <= M_PI * 35.0 / 180.0
            && std::atan2( p_l.y(), p_l.x() ) >= -M_PI * 35.0 / 180.0);
}
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
